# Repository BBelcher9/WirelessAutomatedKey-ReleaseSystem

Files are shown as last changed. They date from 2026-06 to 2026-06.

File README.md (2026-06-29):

# Wireless Automated Key-Release System

## Demonstration Video
https://www.youtube.com/watch?v=V6xTp-4p8c4

## Overview
This project is a custom automation systems that combines 3D modeling, embedded programming, and electronics to create a LAN remote controlled key dropping device. This demonstrated an end-to-end engineering workflow from mechanical to programming.

Using an http request, you can control preset movements of the device to release keys remotely.

See Assembly Guide PDF file for construction instructions.

## Hardware
1.	Door x 1 [3D Printed]
2.	GuideSleeve x 1 [3D Printed]
3.	KeyDropEnclosure x 1[3D Printed]
4.	Lid x 1 [3D Printed]
5.	LockPin x 1 [3D Printed]
6.	MotorSleeve x 1 [3D Printed]
7.	PinKnob x 1 [3D Printed]
8.	ESP32 Micro Controller x 1
9.	ESP32 Power Cable x 1
10.	Micro Servo Motor SG90 x 2
11.	M1.7*5 Screw x 6
12.	#6 x 3/8” Screws x 2

## Software
1. Arduino IDE
2. ESP32 Libraries

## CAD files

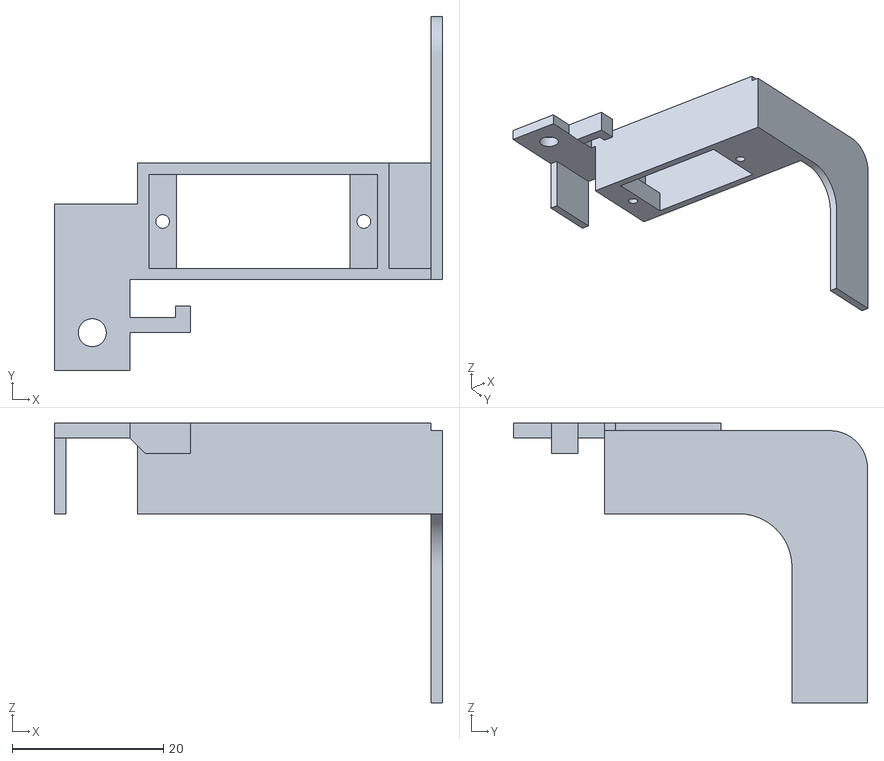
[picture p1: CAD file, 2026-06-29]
3D Files/MotorSleeve.stl
51.3 x 46.8 x 37.0

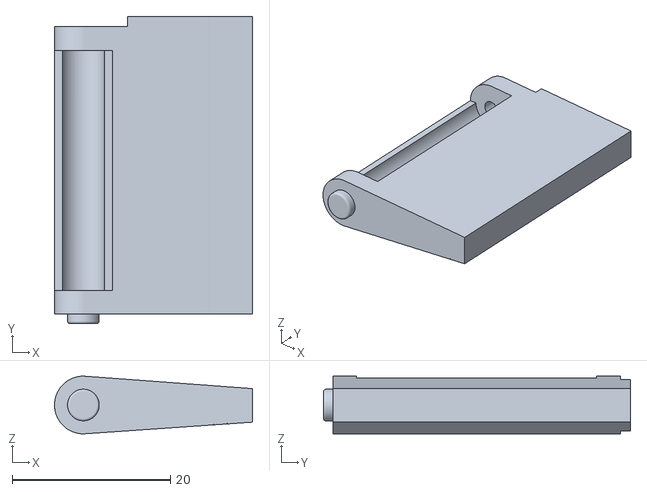
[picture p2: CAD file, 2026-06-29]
3D Files/Door.stl
25.0 x 38.8 x 7.30

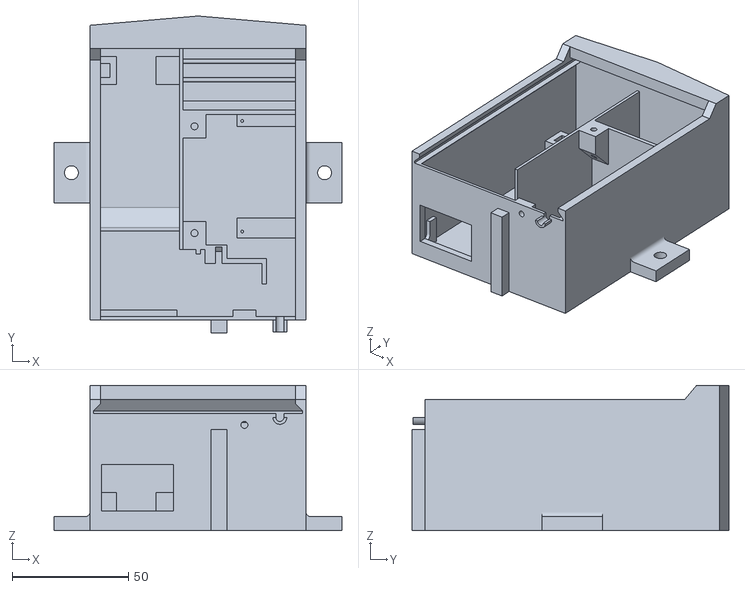
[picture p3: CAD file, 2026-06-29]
3D Files/KeyDropEnclosure.stl
124.0 x 136.5 x 62.5

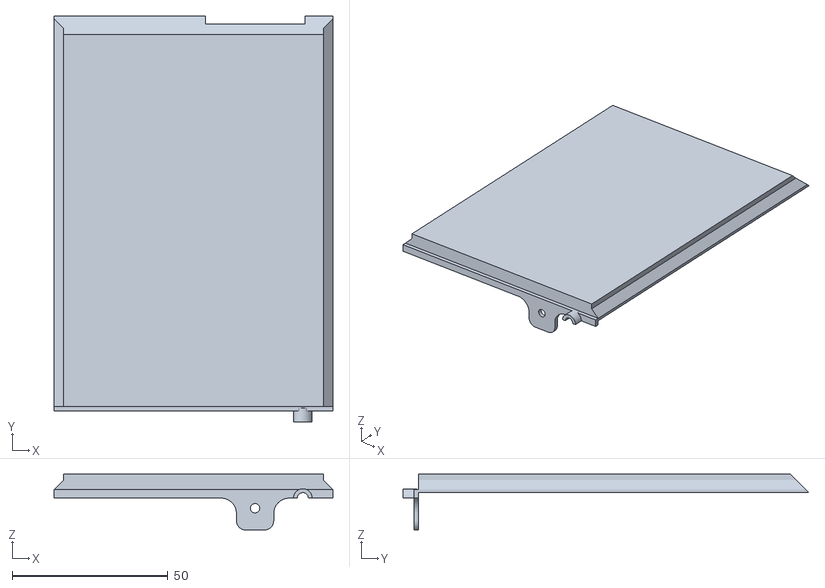
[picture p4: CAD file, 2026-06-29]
3D Files/Lid.stl
89.6 x 130.5 x 18.0

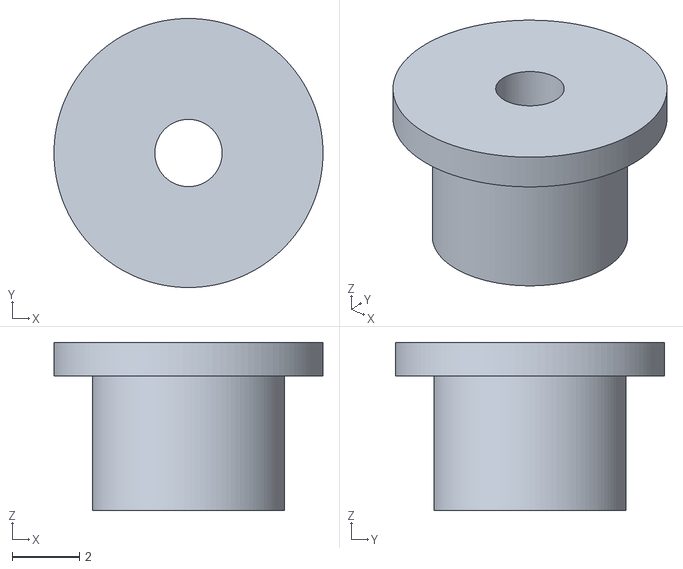
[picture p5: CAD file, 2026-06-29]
3D Files/PinKnob.stl
8.00 x 8.00 x 5.00

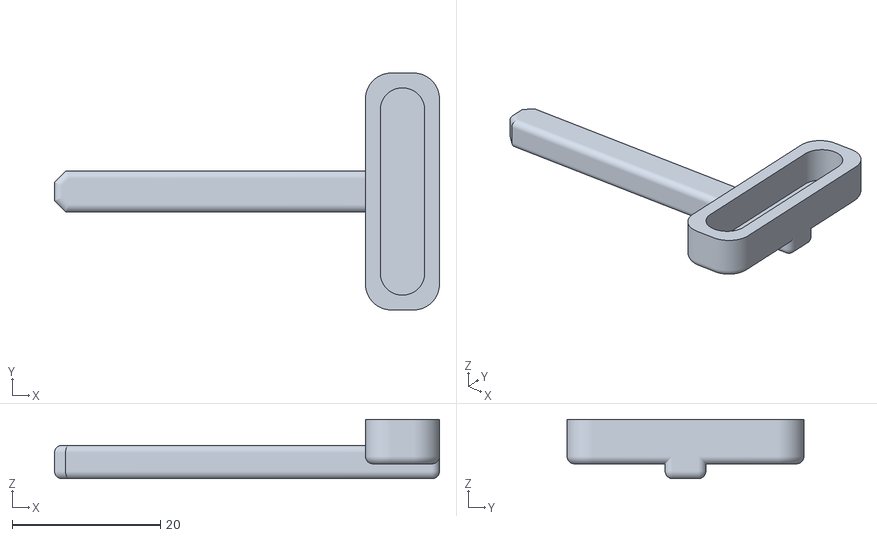
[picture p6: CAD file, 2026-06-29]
3D Files/LockPin.stl
52.0 x 32.0 x 8.00

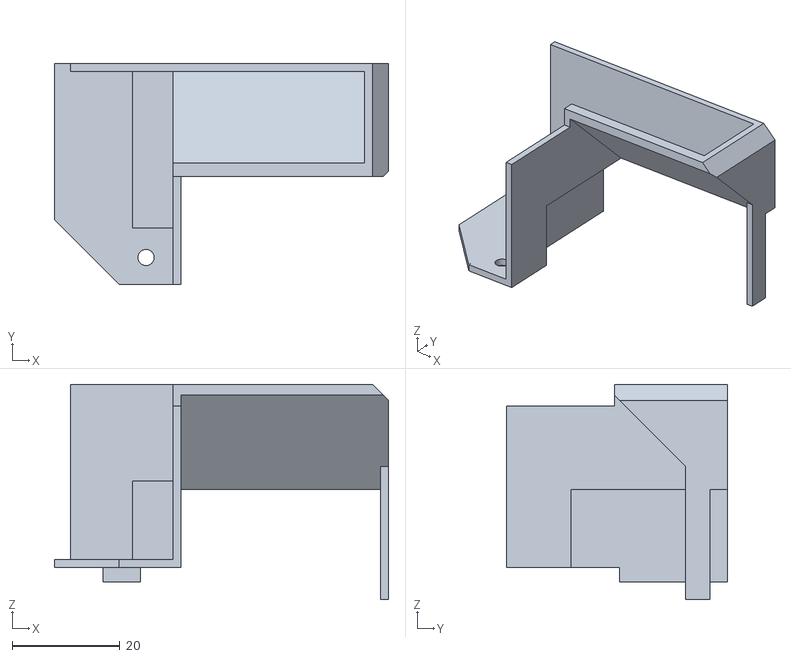
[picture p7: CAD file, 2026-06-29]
3D Files/GuideSleeve.stl
62.0 x 41.0 x 40.0

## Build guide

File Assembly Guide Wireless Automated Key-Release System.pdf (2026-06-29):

# Wireless Automated Key-Release System

# Assembly Guide

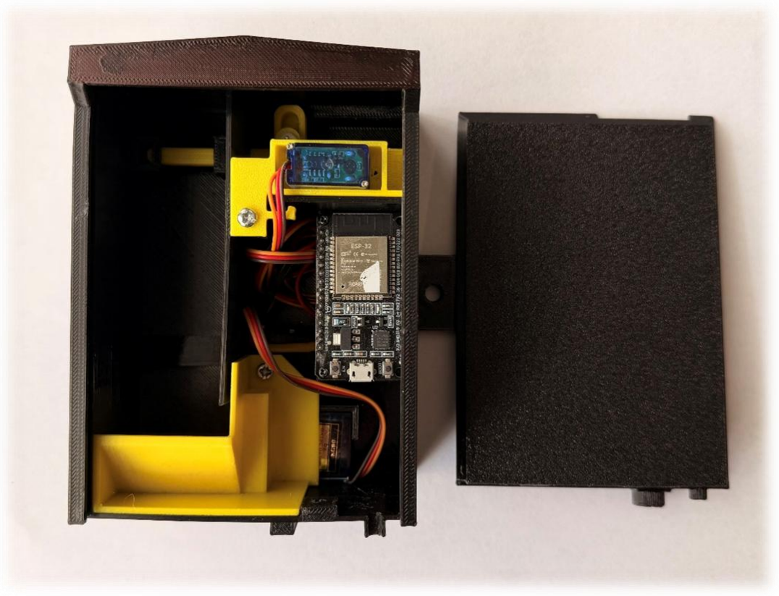
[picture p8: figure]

Designed By: Bryan Belcher

## Contents

## Required Components:

1. Door x 1 [3D Printed]
2. GuideSleeve x 1 [3D Printed]
3. KeyDropEnclosure x 1[3D Printed]
4. Lid x 1 [3D Printed]
5. LockPin x 1 [3D Printed]
6. MotorSleeve x 1 [3D Printed]
7. PinKnob x 1 [3D Printed]
8. ESP32 Micro Controller x 1
9. ESP32 Power Cable x 1
10. Micro Servo Motor SG90 x 2
11. M1.7*5 Screw x 6
12. #6 x 3/8” Screws x 2

## Additional Notes:

- Print all 3D printed components in a high-temperature capable filament. For this I am using Creality PETG.
- Slight screw size variation may be allowed as material is plastic.
- If the assembly is installed in an area exposed to weather, applying a resin coat to the top surface can help protect it.

## Demonstration Video:

YouTube Link

## Wiring Diagram:

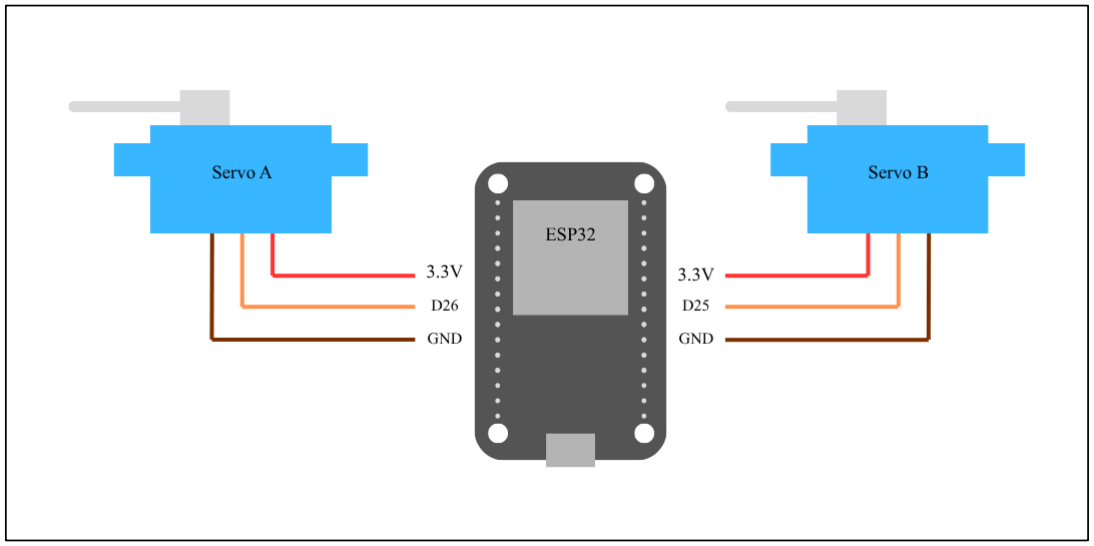
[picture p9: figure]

## Controlling Command:

Example:

http://[Local IP address]/[function]?key=[Password]

http://192.168.01.123/drop?key=p@ssw0rd

## Step 1:

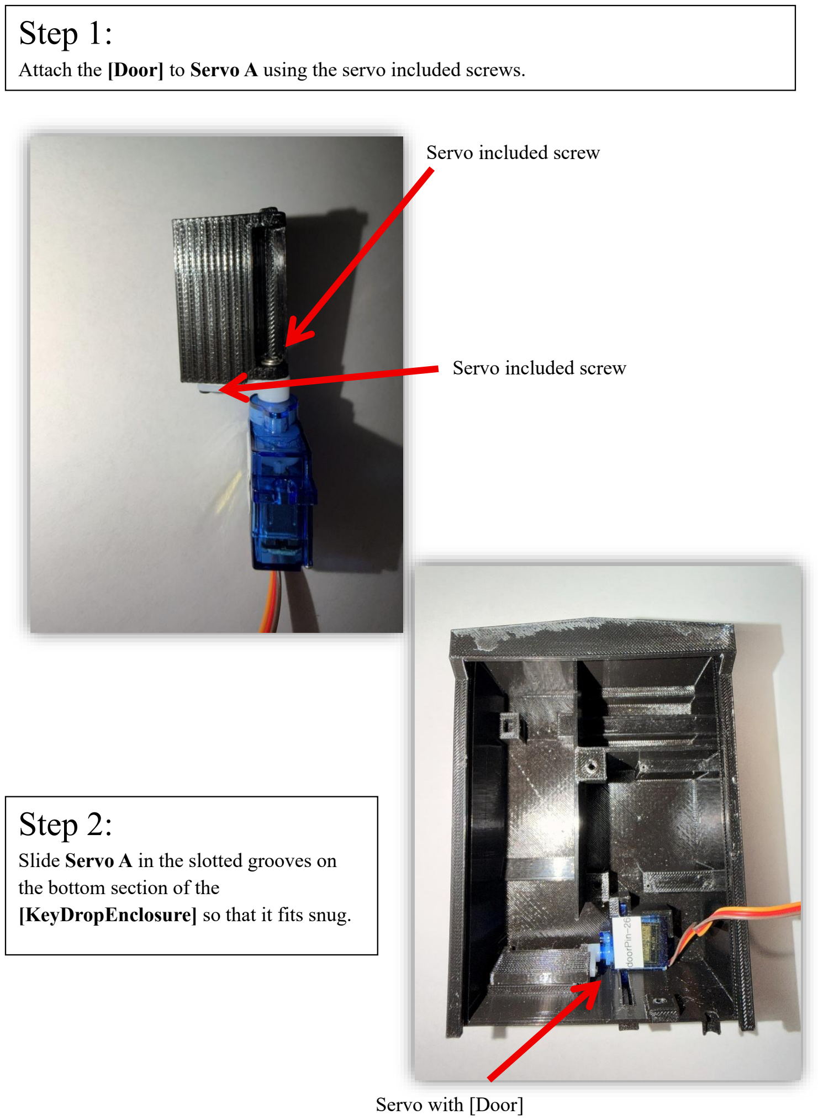
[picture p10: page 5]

Attach the [Door] to Servo A using the servo included screws.

## Step 2:

Slide Servo A in the slotted grooves on the bottom section of the
[KeyDropEnclosure] so that it fits snug.

Servo included screw

Servo included screw

Servo with [Door]

## Step 3:

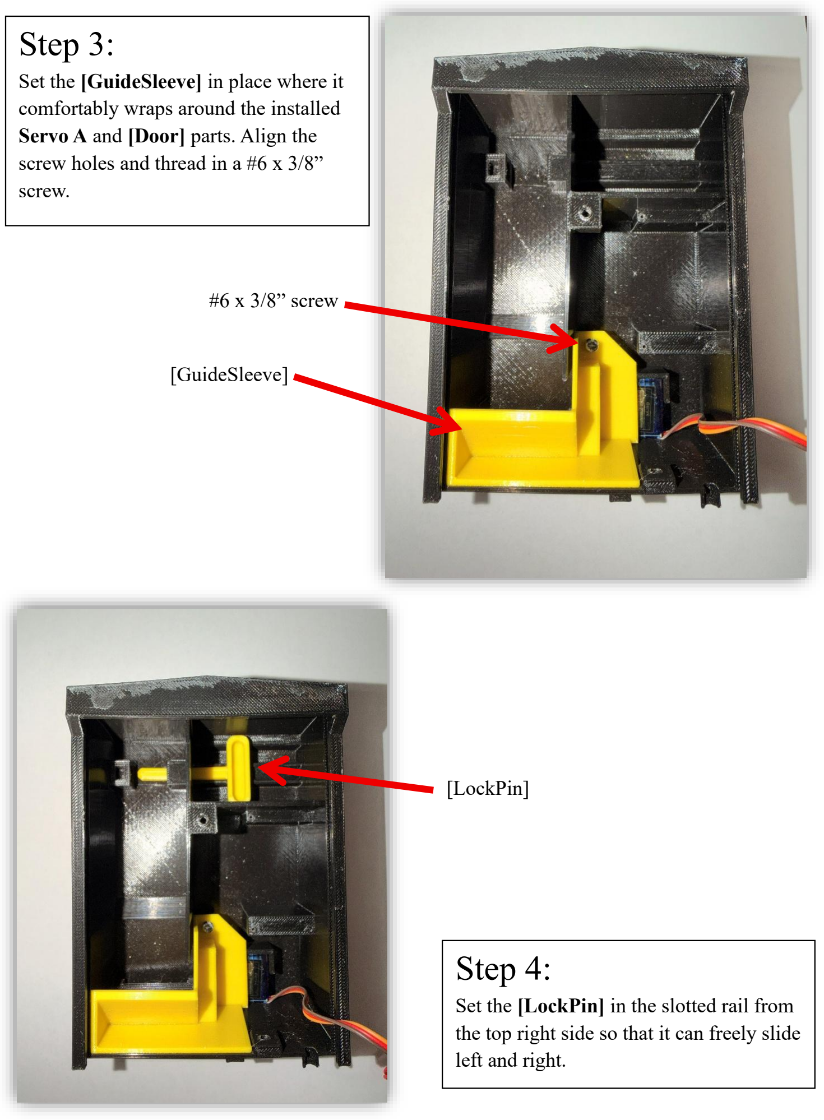
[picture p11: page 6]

Set the [GuideSleeve] in place where it comfortably wraps around the installed Servo A and [Door] parts. Align the screw holes and thread in a #6 x 3/8” screw.

#6 x 3/8” screw

[GuideSleeve]

## Step 4:

Set the [LockPin] in the slotted rail from the top right side so that it can freely slide left and right.

[LockPin]

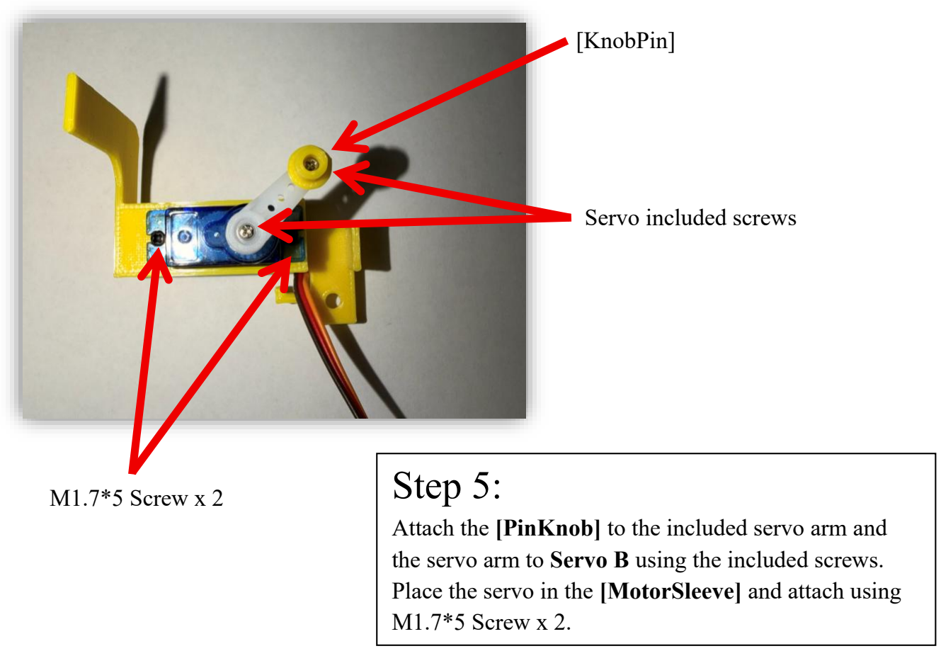
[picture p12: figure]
Step 5:; M1.7*5 Screw x 2.; [KnobPin]; M1.7*5 Screw x 2; Servo included screws

Attach the [PinKnob] to the included servo arm and the servo arm to Servo B using the included screws. Place the servo in the [MotorSleeve] and attach using

## Step 6:

Set Servo B and [MotorSleeve] into the top right opening with the [PinKnob] sitting in the [LockPin] groove. Screw the [MotorSleeve] in place using a #6 x 3/8” screw.

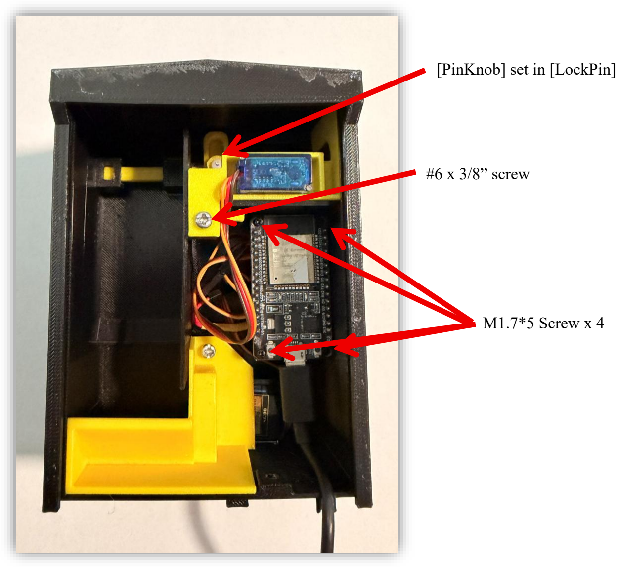
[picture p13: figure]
[PinKnob] set in [LockPin]; #6 x 3/8” screw; M1.7*5 Screw x 4

## Step 7:

Wire the two servo motors to the ESP32 controller according to the Wiring Diagram. Screw the ESP32 controller to the [KeyDropEnclosure] using M1.7*5 Screw x 4.

## Step 8:

Connect the ESP32 and a computer using the data transferable Power Cable and upload the GitHub provided project program to the ESP32.

Adjustments to the program file is required to allow network access. Servo angle changes in program file may also be necessary. Arduino IDE is a great tool for this.

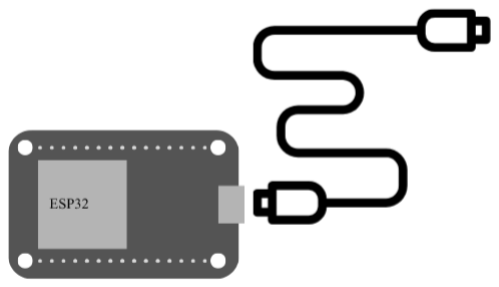
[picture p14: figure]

## Step 9:

Slide the [Lid] over the assembly, then secure it by driving a #6 x 3/8” screw into the designated screw hole.

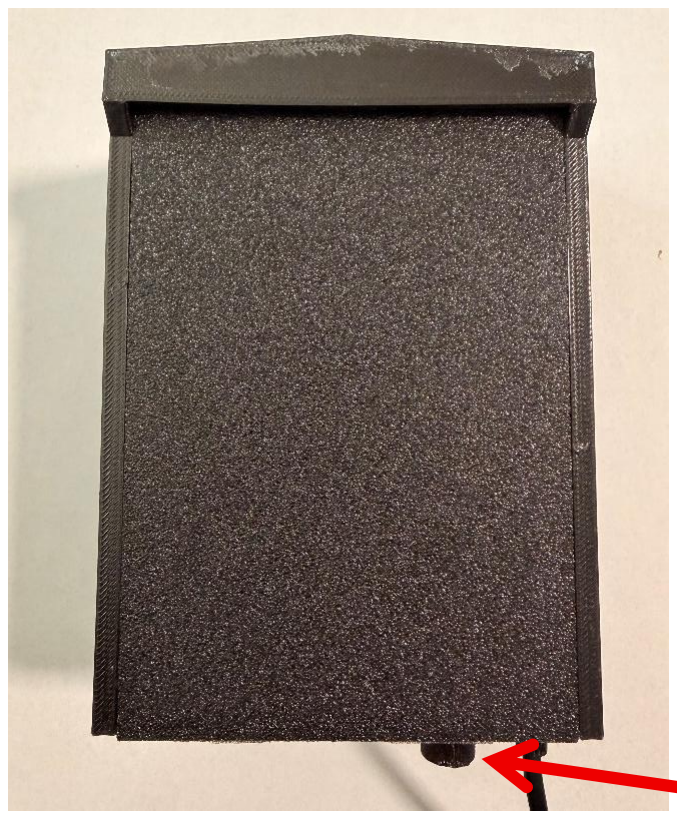
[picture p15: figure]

M1.7*5 Screw x 1

Examples:

## Step 10:

After statically assigning the IP address in your router’s settings, activate the mechanism by the running the Controlling Command from a device on the local network.

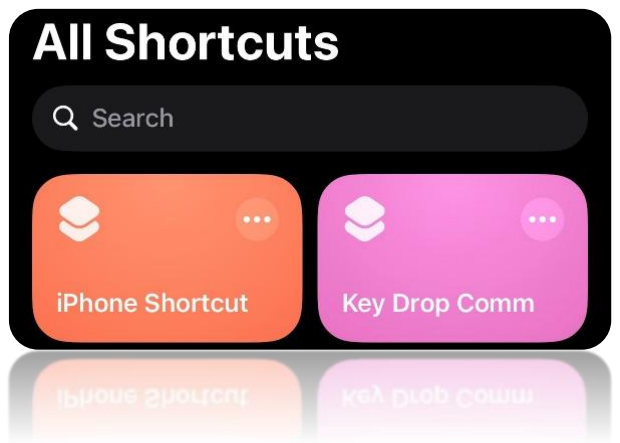
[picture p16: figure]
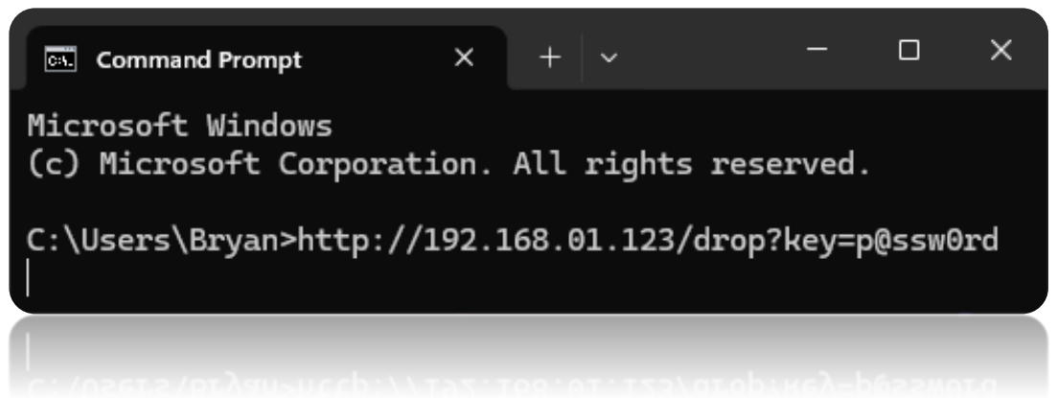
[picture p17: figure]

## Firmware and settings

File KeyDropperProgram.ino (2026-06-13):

/*
  Servos will move to a reset position after its been detached. Because of this, I placed the detach before the server.send. 
  For some reason, having something else happen immediately after helps stop the motors from moving after detached.

*/

// Declare Libraries
#include <WiFi.h>
#include <WebServer.h>
#include <ESP32Servo.h>

// Connection and Verifications
const char* ssid = "WiFi Name";
const char* password = "WiFi Password";
const char* secretKey = "Your Remote Command Password";

// Configure servo, pin, and angle presets
Servo hookServo;    //pin 25
Servo doorServo;    //pin 26
const int hookPin = 25;
const int doorPin = 26;
int angHookOpen = 150;
int angHookClose = 38;
int angDoorOpen = 157;
int angDoorClose = 34;

// Server port
WebServer server(80);

// === HANDLERS ===
void handleDrop() {
  if (server.arg("key") == secretKey) {
    hookServo.attach(hookPin);
    doorServo.attach(doorPin);
    // Open door
    doorServo.write(angDoorOpen);
    delay(1000);

    // Pin and reset pin
    hookServo.write(angHookOpen);
    delay(1000);
    hookServo.write(angHookClose);
    delay(1000);

    // Close door
    doorServo.write(angDoorClose);
    delay(1000);

    // Detach servos
    hookServo.detach();
    doorServo.detach();
 
    server.send(200, "text/plain", "Supply Drop");
  } else {
    server.send(403, "text/plain", "Forbidden");
  }
}

void handleOpenPin() {
  if (server.arg("key") == secretKey) {
    hookServo.attach(hookPin);
    hookServo.write(angHookOpen);
    delay(1000);
    hookServo.detach();
    server.send(200, "text/plain", "Pin Open");
  } else {
    server.send(403, "text/plain", "Forbidden");
  }
}

void handleClosePin() {
  if (server.arg("key") == secretKey) {
    hookServo.attach(hookPin);
    hookServo.write(angHookClose);
    delay(1000);
    hookServo.detach();
    server.send(200, "text/plain", "Pin Closed");
  } else {
    server.send(403, "text/plain", "Forbidden");
  }
}

void handleOpenDoor() {
  if (server.arg("key") == secretKey) {
    doorServo.attach(doorPin);
    doorServo.write(angDoorOpen);
    delay(1000);
    doorServo.detach();
    server.send(200, "text/plain", "Closed");
  } else {
    server.send(403, "text/plain", "Forbidden");
  }
}

void handleCloseDoor() {
  if (server.arg("key") == secretKey) {
    doorServo.attach(doorPin);
    doorServo.write(angDoorClose);
    delay(1000);
    doorServo.detach();
    server.send(200, "text/plain", "Closed");
  } else {
    server.send(403, "text/plain", "Forbidden");
  }
}

void setup() {
  // Begin WiFi connection
  Serial.begin(115200);
  WiFi.begin(ssid, password);
  while (WiFi.status() != WL_CONNECTED) {
    delay(500);
  }

  // Preset commands
  server.on("/drop", handleDrop);
  server.on("/openPin", handleOpenPin);
  server.on("/closePin", handleClosePin);
  server.on("/openDoor", handleOpenDoor);
  server.on("/closeDoor", handleCloseDoor);
  server.begin();
}

void loop() {
  server.handleClient();
  delay(500);
}
